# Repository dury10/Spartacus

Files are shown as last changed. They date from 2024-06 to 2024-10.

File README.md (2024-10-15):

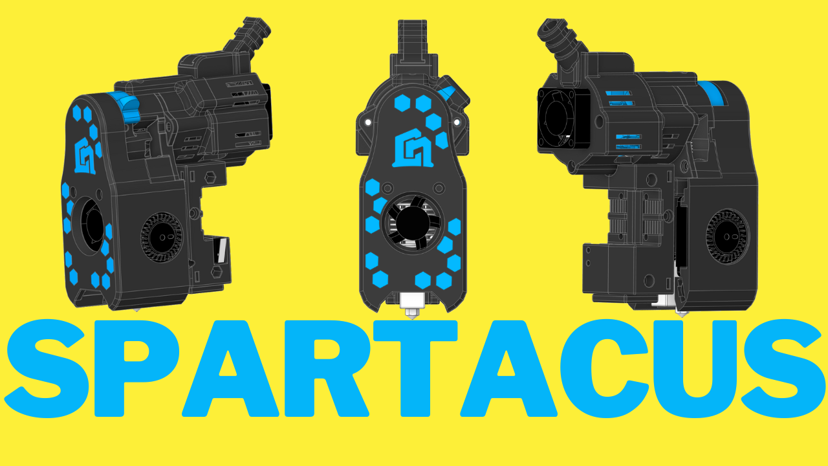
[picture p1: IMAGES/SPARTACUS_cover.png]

 
Later edit : 
added Rapido UHF as an option for the hotend 
we have added Eddy Support 
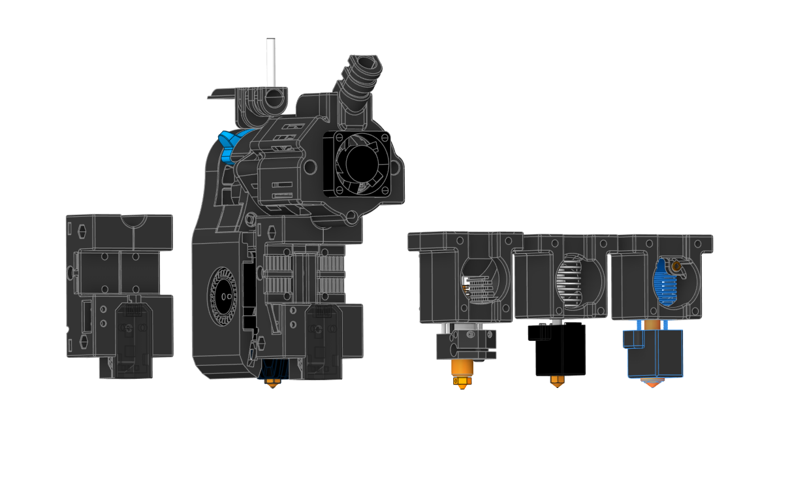
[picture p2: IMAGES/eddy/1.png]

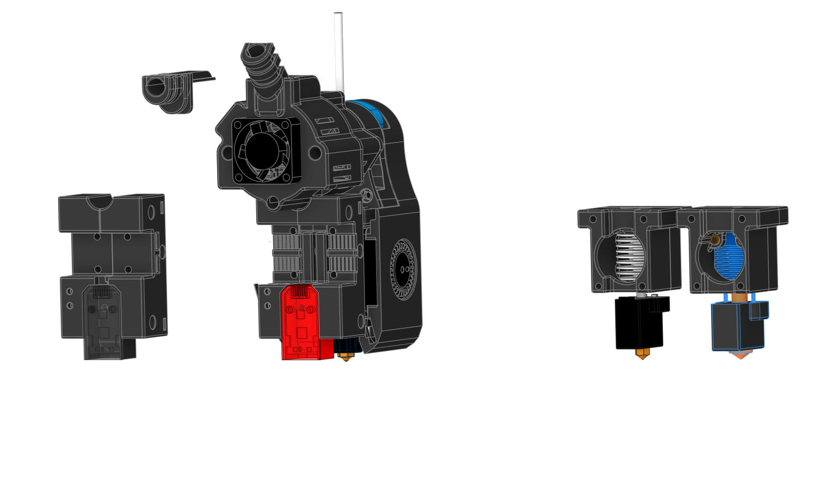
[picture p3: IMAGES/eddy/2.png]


### Hello Everyone 

This is my take on building a small toolhead:
A project I have been working on for more than a year. It all  started when Voron Design launched V0.2 with the Mini StealthBurner
I liked that toolhead a lot but I wanted more. 
More Flow, more cooling and more features like LED and this is how i ended with CN3D 4010 Mini StealtBurner.
I always liked the idea to get out the most from anything I encounter.  I looked for a way to be on the budget and to achieve better quality and reasonable speeds. 
I will not talk more about the last year project but it’s important to let you know how I got to Spartacus!

After I managed to add in MSB everything that in my opinion was missing I thought “what if i’d have all of these in a smaller and lighter form?”. And this is how I ended up with a lighter  and narrower toolhead.

### Who is this Toolhead for? 

This is for someone who wants a light toolhead that looks good ,without messy cables,  tidy and has visible and lighted nozzle, that you can build with off the shelf components that doesn’t require a lot of money. 
I found a solution for every situation i have encountered on my journey to print fast on a budget. 

### Now, to correct what i said :
I didn’t crafted all the parts that I have used to create this toolhead. I just tested a lot to find the cheapest version to achieve  the results I was aiming for. 

### I got a lot of questions about the difference from the stock design. 

- It has bigger part cooling fans. I went further and I removed the cover from the fans and used the cowling as a fan cover.
- It has 2 neopixels.
- It has built in cable management and covers to hide all the messy spaghetti.
- It has passive cooling for the stepper motor, and all the flow/air from the hotend fan is routed to go up out of the build plate.
- It has different position for the idler gear to reduce some artifacts.

### It can be installed on any Voron v2.4 or trident or any other 3d printer that uses this gantry style. 

### The design goal:
- to have all of the above in less than 320 grams 
- to have a minimum flow of 35mm3/s and all the parts used to build this toolhead to be less than 120Euros.

 Spartacus: The Toolhead stands as a testament to lightweight engineering mastery, boasting a total weight of under 320 grams, with the potential to further reduce weight by implementing titanium screws. Every component, from the stepper motor to the thermistor, board cables, heater, LEDs, fans, heatsink, nozzle, and screws, has been meticulously crafted to maintain this featherlight profile without compromising on performance or durability. Spartacus redefines the possibilities of 3D printing toolheads, offering a combination of high performance and portability that is unmatched in its class. Dominate your printing projects with Spartacus: where innovation meets lightweight precision.

 Engineered with precision, Spartacus integrates a multitude of features including dual RGBW LEDs, direct drive capabilities, and an appealing aesthetic with concealed cables and motor covers. Compatible with both EBB36 and Piggyback 36 toolboards, Spartacus offers versatility without compromise. Weighing under 320 grams, its agile form minimizes inertia, enabling rapid accelerations and pristine print quality, free from artifacts. Unleash the power of Spartacus: where innovation meets agility.

## Key Features:

- Powerful direct drive extruder for rapid printing (Flow tested up to 55mm³/s)
- Utilizes the T-Volcano hotend for increased flow and faster prints
- Enhanced cooling with 3010 and dual 4010 GDS Time 12000 rpm fans
- Lightweight and compact design inspired by Voron Design (Mini Stealth Burner)
- Cost-efficient, with a total build cost under $75
- Versatile design allows for customization and adaptation to different setups
- 2 Neopixel LED lights for improved visibility and real-time print status updates

## Bill of Materials (BOM):

### Fans:

- 1 x 3010 GDS Time 12000 rpm Fan  https://s.click.aliexpress.com/e/_Dd0TMzH 
- 2 x 4010 GDS Time Blower Fan (12000 rpm dual ball bearing recommended for optimal cooling) https://s.click.aliexpress.com/e/_DevBF23 

### Hotend Components: For the Cheapest way posible hotend up to 32mm3/s without bumping the themperature if you want more use Rapidon 

- 1 x V6 Heat Sink (light weight) https://s.click.aliexpress.com/e/_DdVmCRp 
- 1 x BiMetal Heat Break https://s.click.aliexpress.com/e/_DdDpmGx 
- 1 x T-Volcano Heat Block https://s.click.aliexpress.com/e/_DdFLdPd
- 1 x Volcano Cht Nozzle https://s.click.aliexpress.com/e/_DFfottp
- 1 x Volcano CHT Hard Nozzle  https://s.click.aliexpress.com/e/_DD5d2Bh Best Budget nozzle 
- 1 x 65W Heater Cartridge (or higher) https://s.click.aliexpress.com/e/_DB6KBBH
- 1 x Thermistor Cartridge for V6 Volcano Heater Block 3x15 (PT100 style) NTC 100K M3950 up to 320c https://s.click.aliexpress.com/e/_DDBx7IL
- 1 x Nema 14 Pancake Stepper Motor https://s.click.aliexpress.com/e/_Dk2jz6F 
- 1 x BMG Dual Driver Gear Kit https://s.click.aliexpress.com/e/_DFUPonD 
- 1 x 30mm PTFE Tube 1.9mm ID 4mm OD
- 2 x Round PCB LED (WRGB, RGB, RGBW, WWRGB, etc.)  https://s.click.aliexpress.com/e/_DCkqzJz
- 1 x Ebb 36 Can boad https://s.click.aliexpress.com/e/_DkBHGcb 

### Optional Add-ons:

- Piggyback/Breakout Board ($9) 
- End caps for cable management based on your setup and chosen board an some cable management wrap 
- 1 x PT1000 Probe 3mm * 15mm Up to 450 Degree RTD 1m Platinum Thermal Resistance Sensor For 3D Printer Volcano/ V6 Heater Block https://s.click.aliexpress.com/e/_DeoYaER 

### Nozzle / Hotend Options (Optional, depending on preference):

- Volcano Cht Nozzle https://s.click.aliexpress.com/e/_DFfottp
- Volcano CHT Hard Nozzle  https://s.click.aliexpress.com/e/_DD5d2Bh Best Budget nozzle 
- Rapido UHF added https://s.click.aliexpress.com/e/_DdN6yC7  
  
## Hardware:

### Heatset Inserts:

- 1 x M3 x 5.7 x 4.5/4.6 Heatset Insert
- 8 x M3 x 3 x 4.5 Heatset Insert

### M3 Screws:  

- 3 x M3 x 6
- 5 x M3 x 10
- 3 x M3 x 25
- 1 x M3 Hex Nut
M3  Screws Kit https://s.click.aliexpress.com/e/_DBdNTVD   

#### This versatile and feature-packed 3D printer tool head provides an affordable solution for high-quality, high-speed printing, enhanced by Neopixel LED lights for improved visibility and dynamic print status updates.

#### Assembly of Spartacus requires minimal tools, including an 1.5mm drill bit, a drill, an angle grinder or hacksaw, and 1.5, 2 and 2.5mm Allen keys. With these tools, users can effortlessly assemble Spartacus and unleash its full potential.

### Here you can see how to build this Awesome Toolead

SPARTACUS (https://www.youtube.com/watch?v=S5xbkWCNOBw)

### If you want to see it in action you can see it here

SPARTACUS (https://www.youtube.com/shorts/Fdcm6XfQ08U)

##  <a href="assembly.md"  >  Assembly guide</a>

If you want to see it in action you will find videos on Tiktok  and Youtube
#### You can follow us on

### Tiktok https://www.tiktok.com/@3dprinttutorials

### Youtube https://www.youtube.com/@nadir3D 

### Facebook https://www.facebook.com/CN3DP/

### Printables https://www.printables.com/@Nadir

CN3D Spartacus is licensed under the
GNU General Public License v3.0
Permissions of this strong copyleft license are conditioned on making available complete source code of licensed works and modifications, which include larger works using a licensed work, under the same license. Copyright and license notices must be preserved. Contributors provide an express grant of patent rights.

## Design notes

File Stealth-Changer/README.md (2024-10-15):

  StealthChanger
**Tool changing system for Sovol SV08 / Vorons and other front mount printer motion systems.**

Here you can find Back Plates to can install Spartacus the toolhead on your Stealt-Changer
keep an eye on this repository more updates to come!
* I want to make this clear here you will find only the parts to can use Spartacus as a toolhead. 
* The toolchanger sistem is not made by us and we don't want to take credit for it! This is the work of the DraftShift theam https://github.com/DraftShift/StealthChanger

Our file that are 100% open source and are work in progress. Spartacus BMG is free and we have listed also the cad file for it. 

<div align="center">
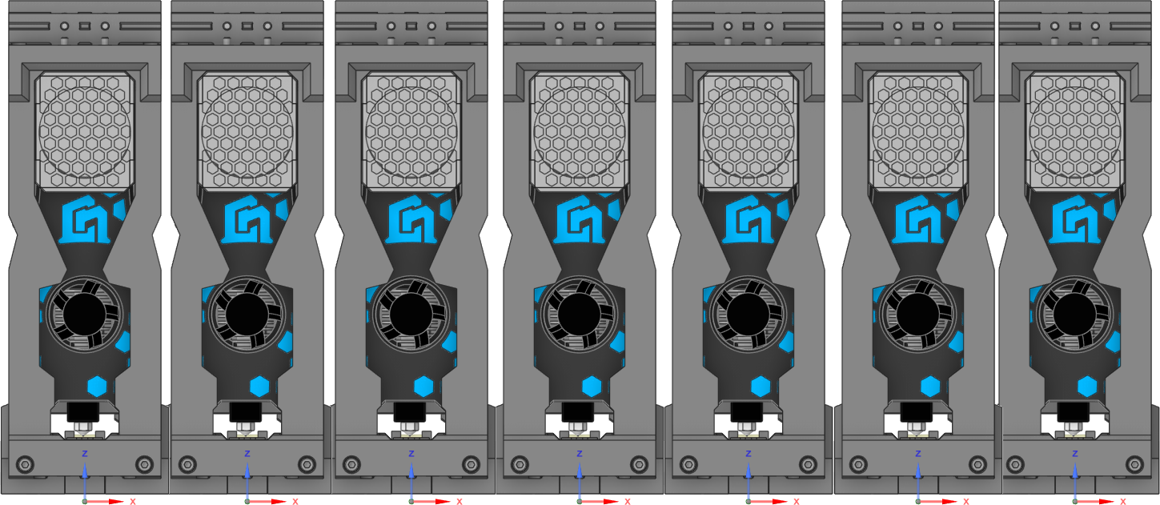
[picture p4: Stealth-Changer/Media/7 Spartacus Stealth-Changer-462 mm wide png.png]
  
</div>

## The Dock is 66mm Wide the Spartacus toolhead is 53 mm wide and 116 mm height  
<div align="center">
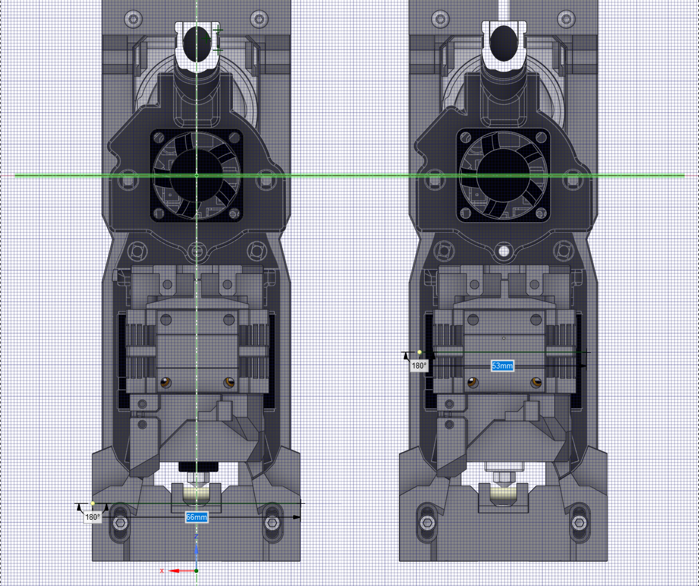
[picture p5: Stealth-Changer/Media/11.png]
 
</div>

 <table border="0"> 
        <tr> 
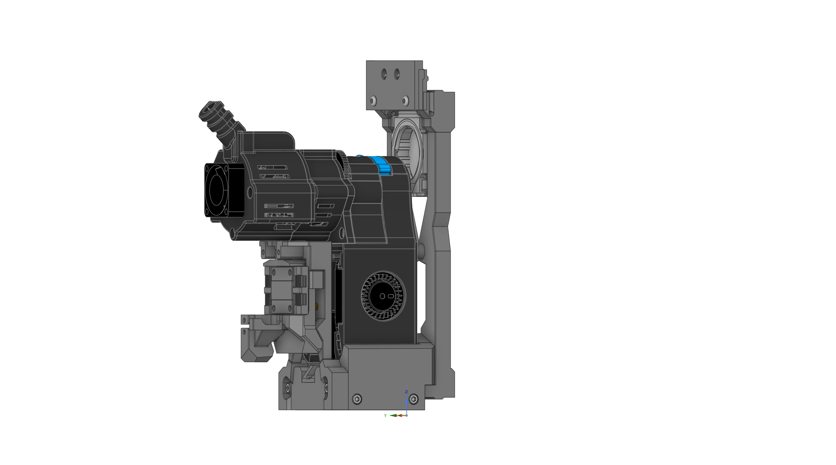
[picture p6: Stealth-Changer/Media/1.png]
            <th></th> 
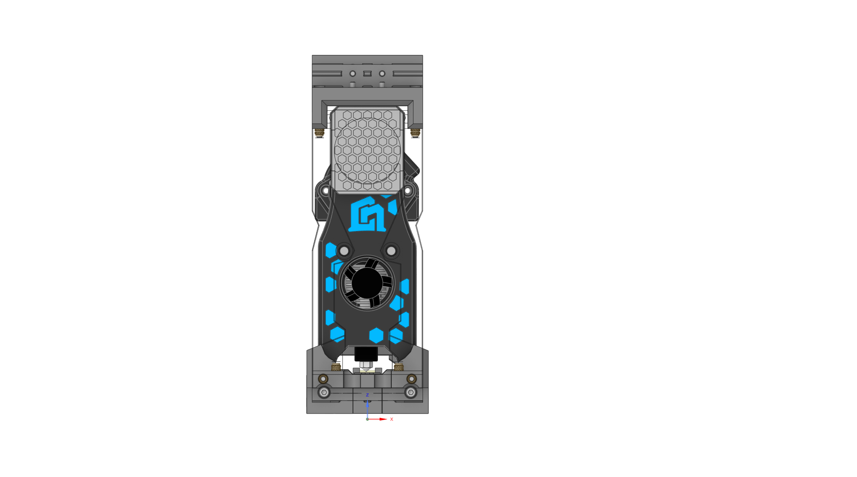
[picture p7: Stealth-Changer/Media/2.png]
            <th></th> 
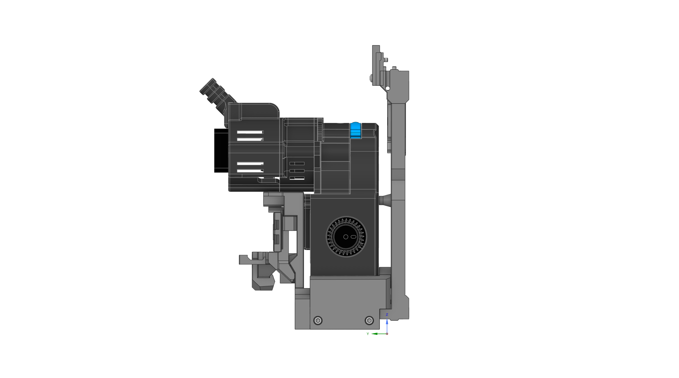
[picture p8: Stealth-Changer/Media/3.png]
            <th></th> 
        </tr> 
        <tr> 
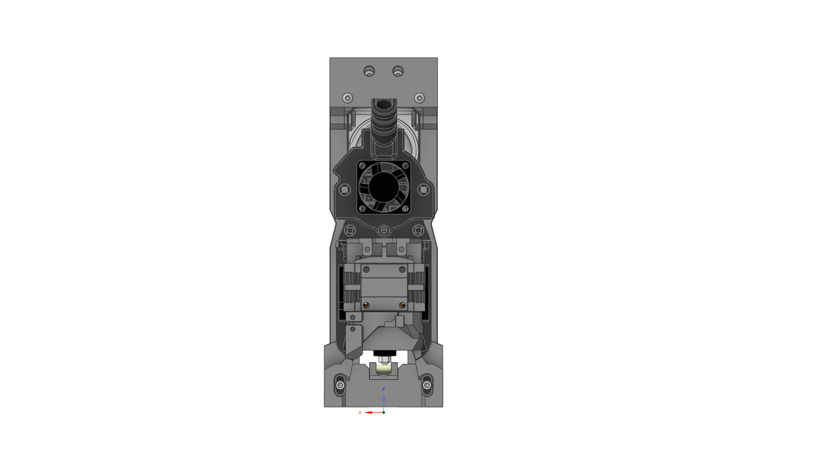
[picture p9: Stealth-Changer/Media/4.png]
            <td> </td> 
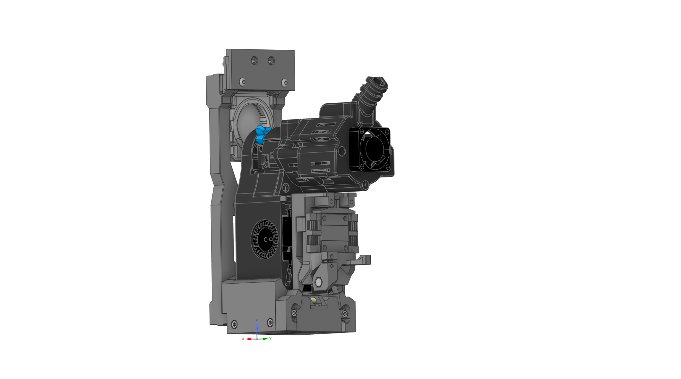
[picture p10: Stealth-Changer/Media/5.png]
            <td></td> 
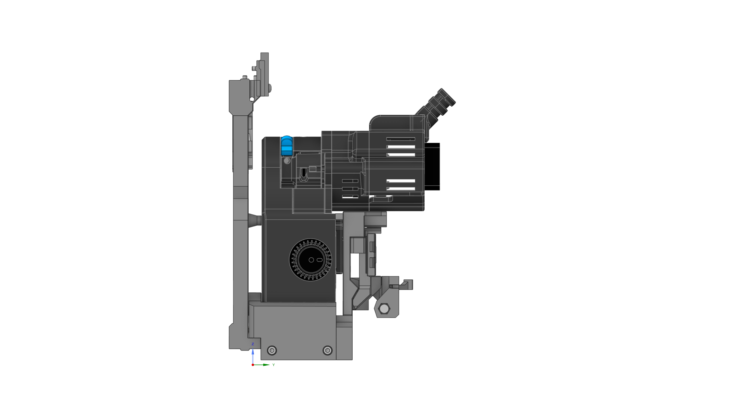
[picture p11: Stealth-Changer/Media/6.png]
            <td> </td> 
        </tr> 
        <tr> 
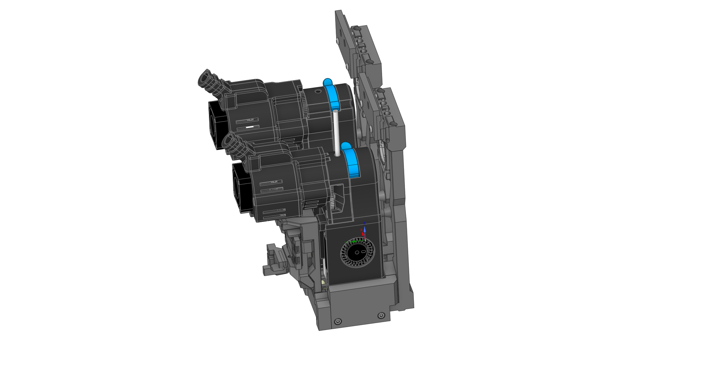
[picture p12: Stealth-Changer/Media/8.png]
            <td>  </td> 
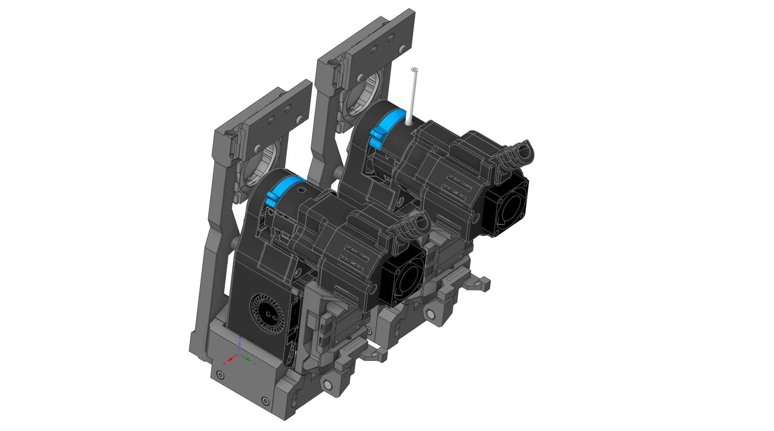
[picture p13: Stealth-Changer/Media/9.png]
            <td></td> 
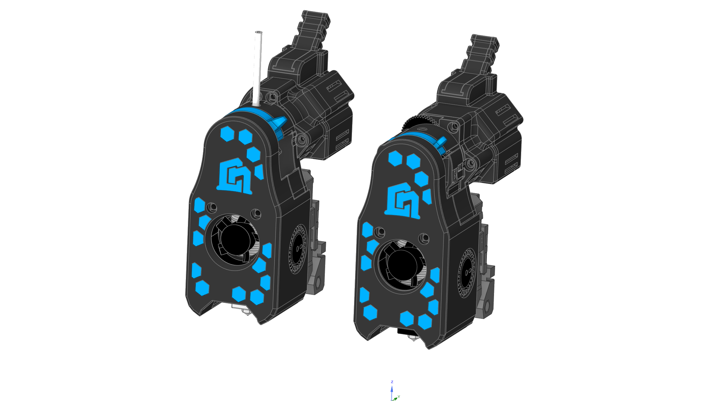
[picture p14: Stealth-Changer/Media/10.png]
            <td>  </td> 
        </tr> 
         <tr> 
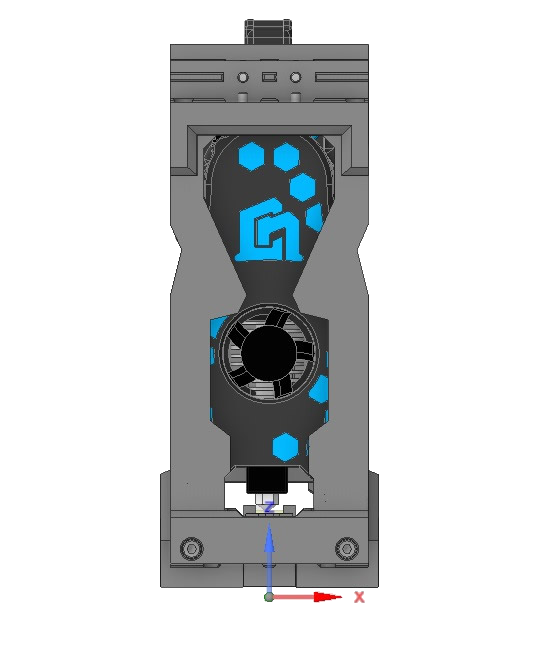
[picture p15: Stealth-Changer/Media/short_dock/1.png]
            <td>  </td> 
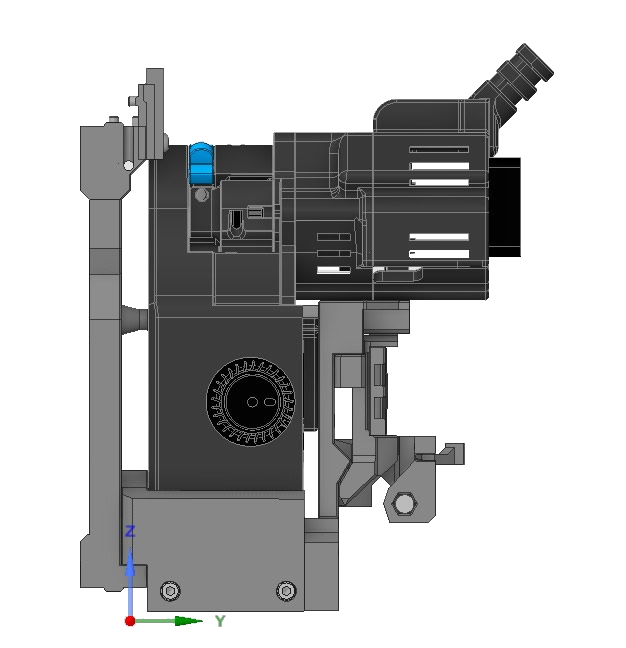
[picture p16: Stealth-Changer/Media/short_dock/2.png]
            <td></td> 
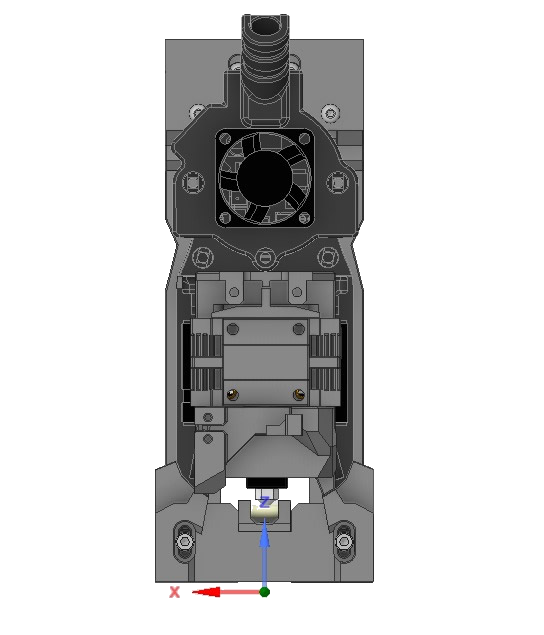
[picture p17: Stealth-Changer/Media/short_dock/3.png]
            <td>  </td> 
        </tr> 
              <tr> 
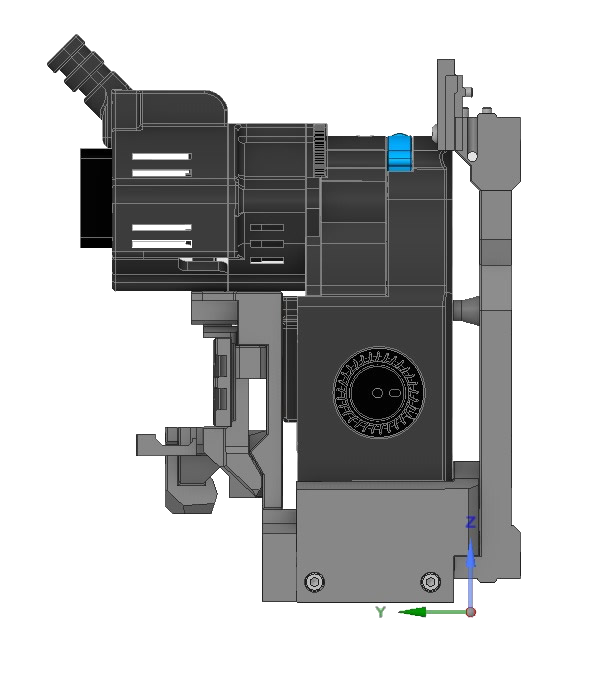
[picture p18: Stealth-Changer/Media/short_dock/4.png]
            <td>  </td> 
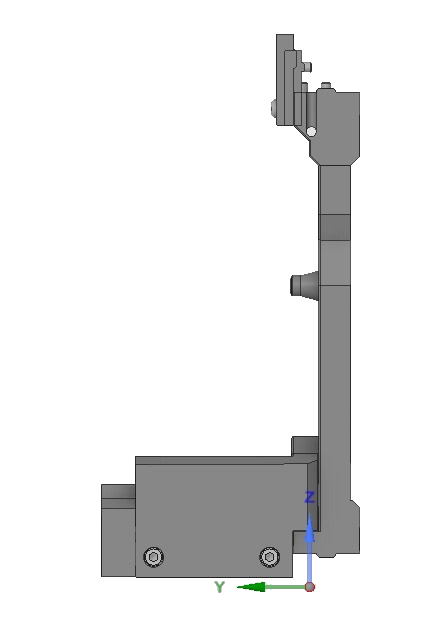
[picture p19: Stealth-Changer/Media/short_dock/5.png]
            <td></td> 
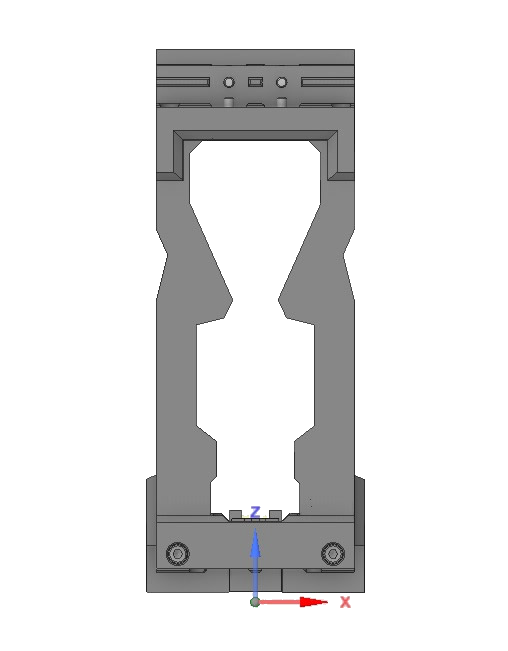
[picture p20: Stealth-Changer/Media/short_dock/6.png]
            <td>  </td> 
        </tr> 

<tr> 
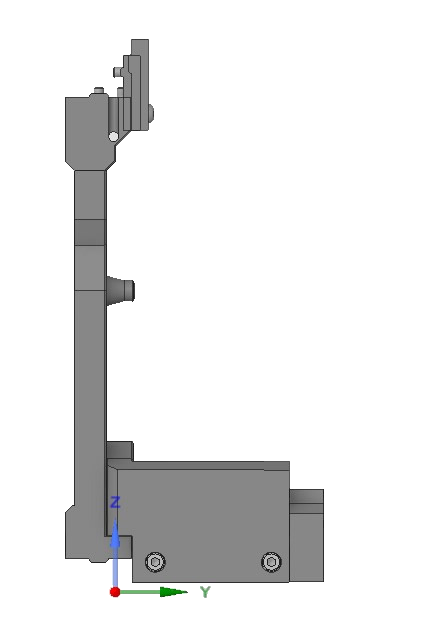
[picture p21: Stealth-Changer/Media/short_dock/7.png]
            <td>  </td> 
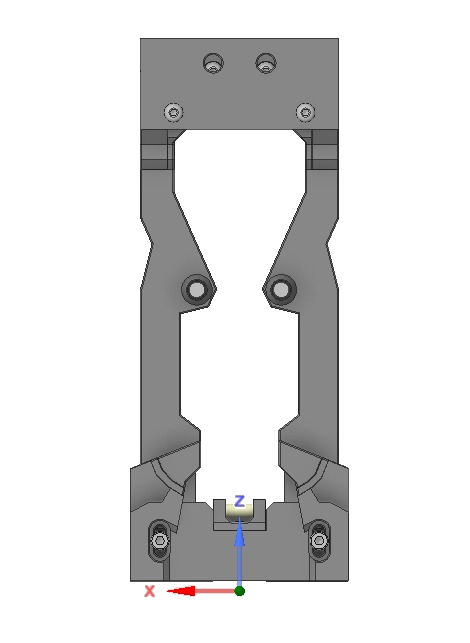
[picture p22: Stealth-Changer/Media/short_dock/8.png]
            <td> </td> 
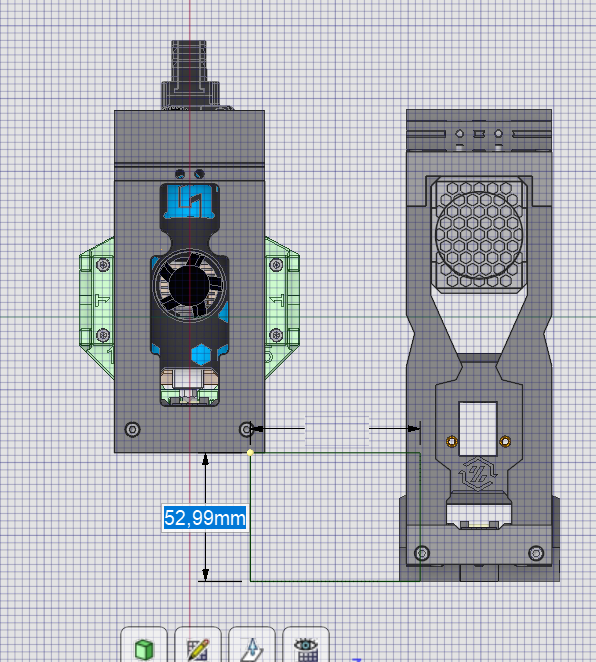
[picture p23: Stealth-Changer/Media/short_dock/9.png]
            <td>  </td> 
 </tr> 

</table> 

* Here you can have hi-quality STL for Spartacus BMG
https://www.printables.com/model/745412-spartacus-the-toolhead

* Here you can have hi-quality STL for Spartacus LGX
https://www.printables.com/model/900809-spartacus-lgx

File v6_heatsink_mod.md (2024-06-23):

## <p align="left">Step by step how to modify your V6 heatsink to fit Spartacus and to be more secure </p>

### 

<br clear="both">

<p>here we have the most common V6 heatsinks</p>
<div align="center">

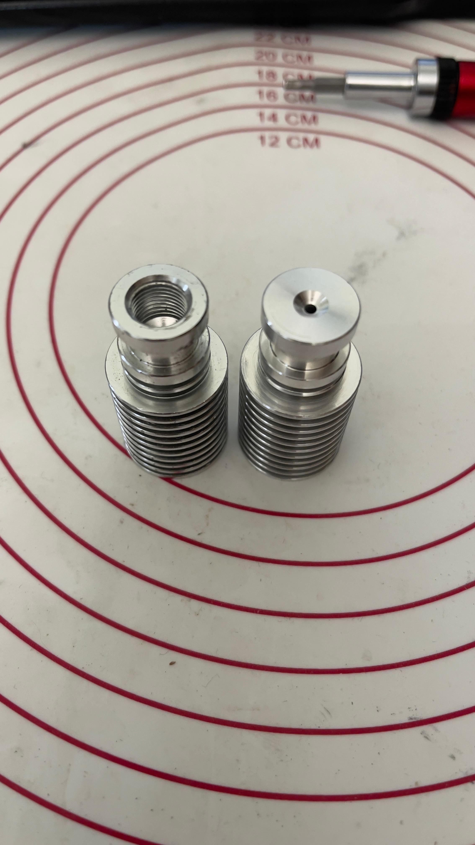
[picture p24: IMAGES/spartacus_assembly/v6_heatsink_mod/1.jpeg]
  
</div>

<p>Bowden and Direct drive Style </p>

<div align="center">
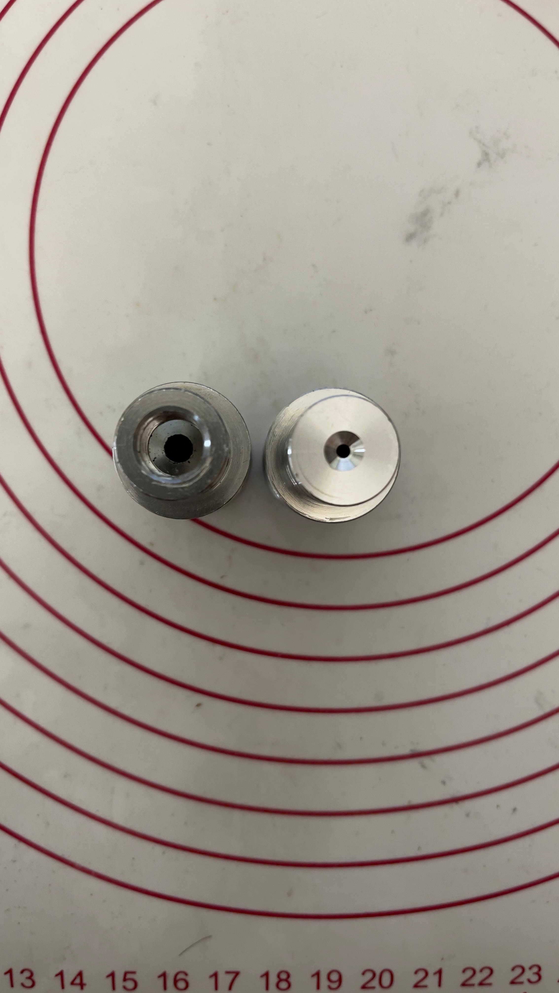
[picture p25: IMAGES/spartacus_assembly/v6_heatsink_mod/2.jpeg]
  
</div>

<p>As dimension they are the same</p>

<div align="center">
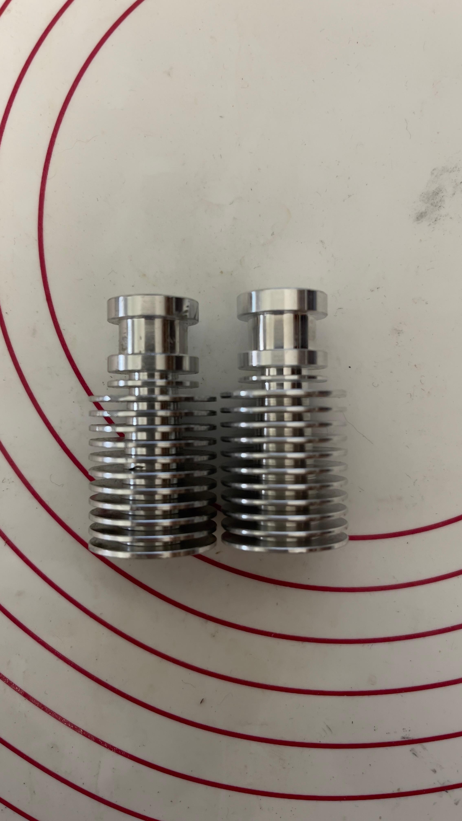
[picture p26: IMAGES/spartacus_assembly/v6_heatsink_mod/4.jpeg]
  
</div>

<p>Here is where we will make the cut</p>

<div align="center">
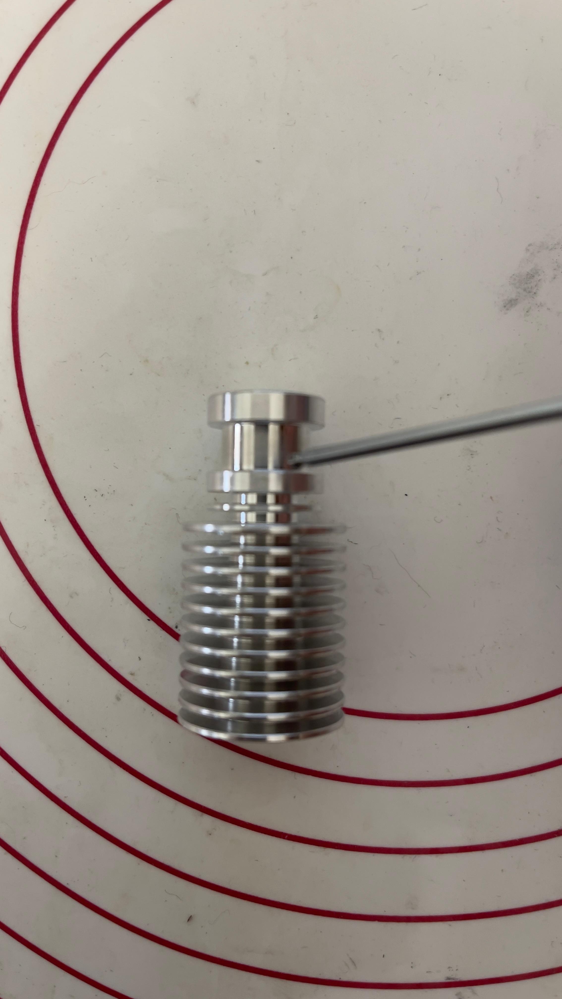
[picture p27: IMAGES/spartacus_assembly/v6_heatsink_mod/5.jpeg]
  
</div>

<p>I have used an angle grinder to cut the upper part, but you can use a hack saw </p>
<div align="center">
  
     

</div>

<p>This is how it is supposed to like after the cut</p>
<div align="center">
  
</div>

<div align="center">
  
</div>

<div align="center">
  
</div>

<p>As you can see i prefer the bowden stile heat sink</p>
<div align="center">
  
</div>

<div align="center">
  
</div>

<div align="center">
  
</div>

<p>Put the heatsink in the V6 Holder </p>
<div align="center">
  
</div>

<div align="center">
  
</div>

<div align="center">
  
</div>

<p>And use 2 M3x40 screw + 2x M3 nuts to secure it in place </p>
<div align="center">
  
</div>

<div align="center">
  
</div>

<div align="center">
  
</div>

<div align="center">
  
</div>

<p>Use a 2.5mm Dril bit and drill 2 holes in the designated locations </p>

<div align="center">
  
</div>

<div align="center">
  
</div>

<div align="center">
  
</div>

<div align="center">
  
</div>

<div align="center">
  
</div>

<p>Clean the debrie and prepare your M3 TAP </p>
<p>Carefully cut some treads 3-5mm </p>

<div align="center">
  
</div>

<div align="center">
  
</div>

<p>After cleaning the threads, now you can screw 2x M3x4, M3x5 or M3x6 I prefer the M3x4 saving weight. </p>

<div align="center">
  
</div>

<p>Remove everything and clean all the mess </p>
<div align="center">
  
</div>

<div align="center">
  
</div>

<p>It should look like this</p>

<div align="center">
  
</div>

<div align="center">
  
</div>

<div align="center">
  
</div>

# <a href="toolhead_assembly.md#Spartacus">Congratuletion now let's asamble the toolhead </a>

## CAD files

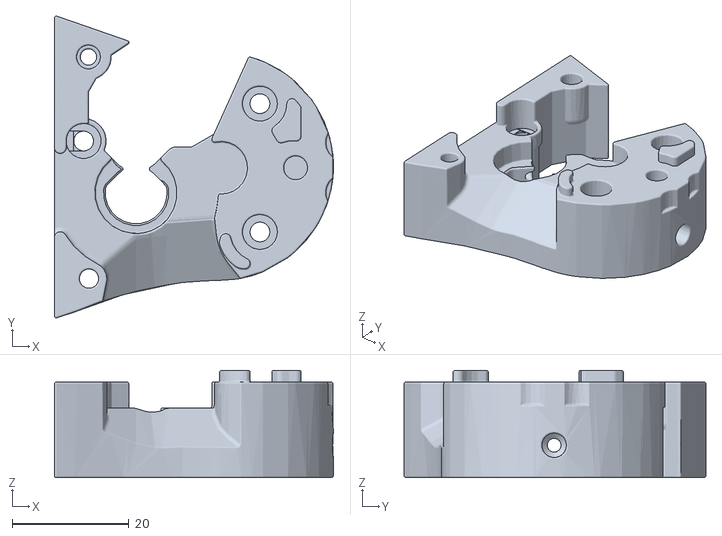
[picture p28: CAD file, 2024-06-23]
STL/extruder_main_body.stl
47.8 x 51.8 x 18.4

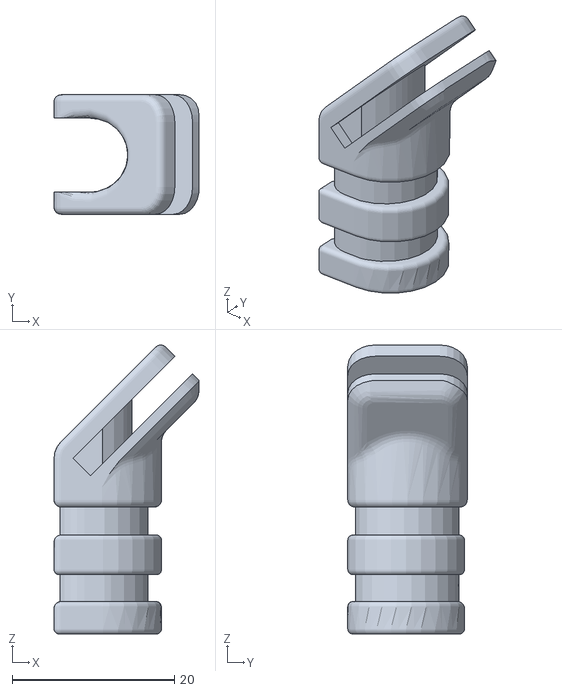
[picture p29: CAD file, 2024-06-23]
STL/strain_relief_45_degres.stl
17.8 x 14.7 x 35.6

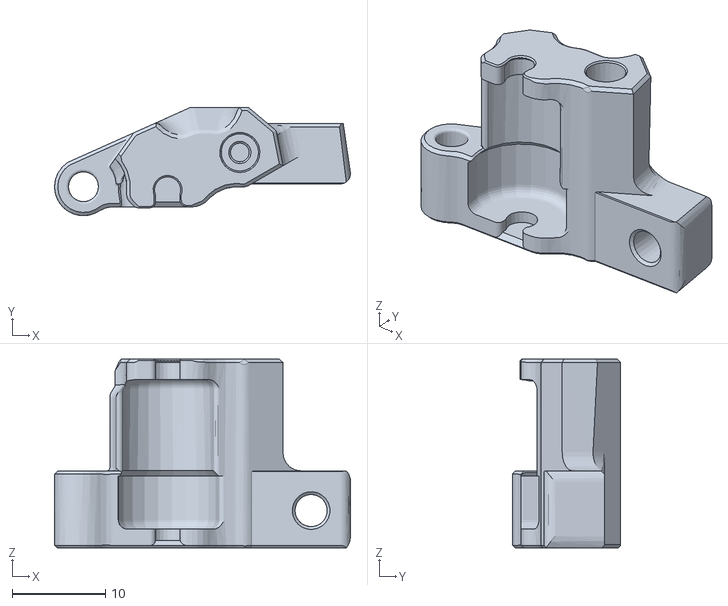
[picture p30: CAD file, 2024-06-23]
STL/idler.stl
31.7 x 11.6 x 20.2

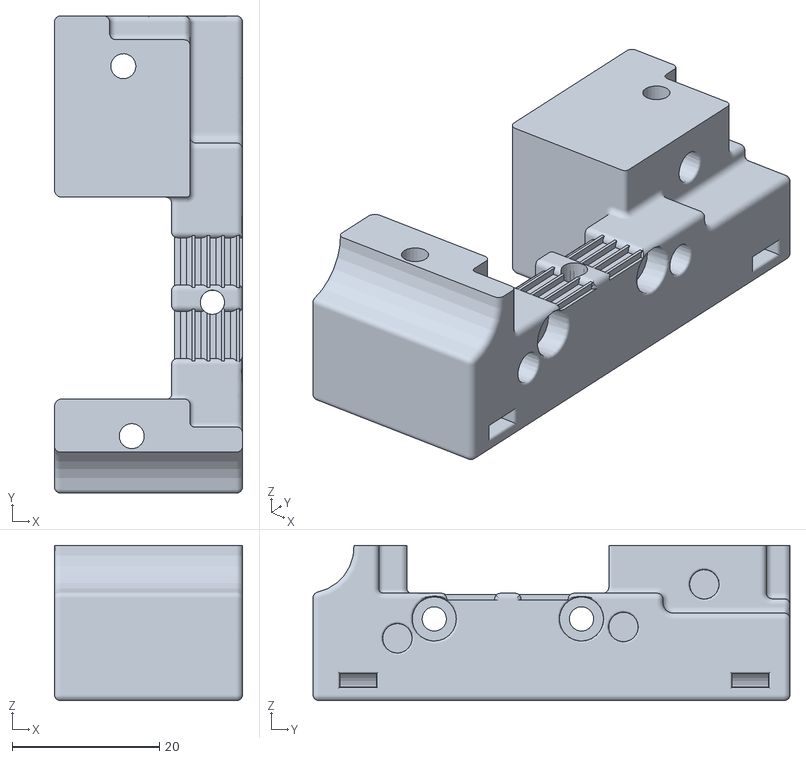
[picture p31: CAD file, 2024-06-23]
STL/MGN12_6mmBelt_X_carriage_Left.stl
25.5 x 64.8 x 21.1

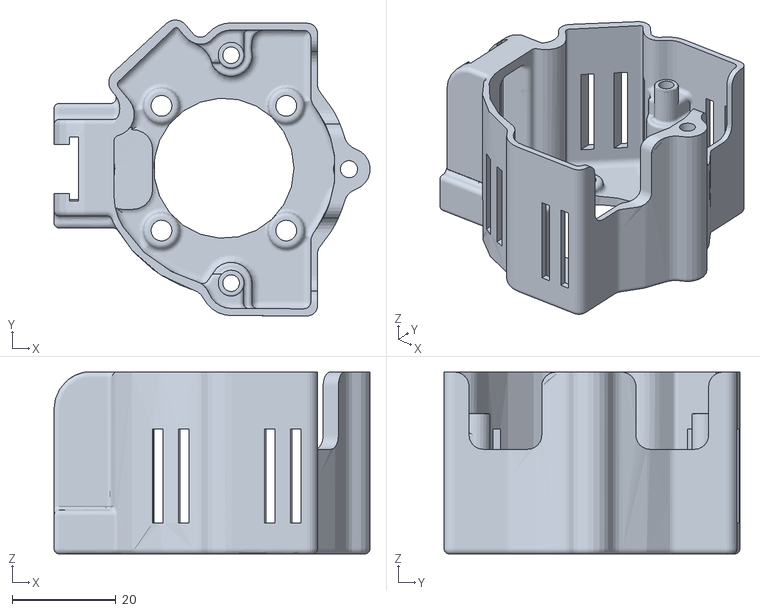
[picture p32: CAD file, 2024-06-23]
STL/ebb_36_can_cover.stl
60.8 x 56.9 x 35.0

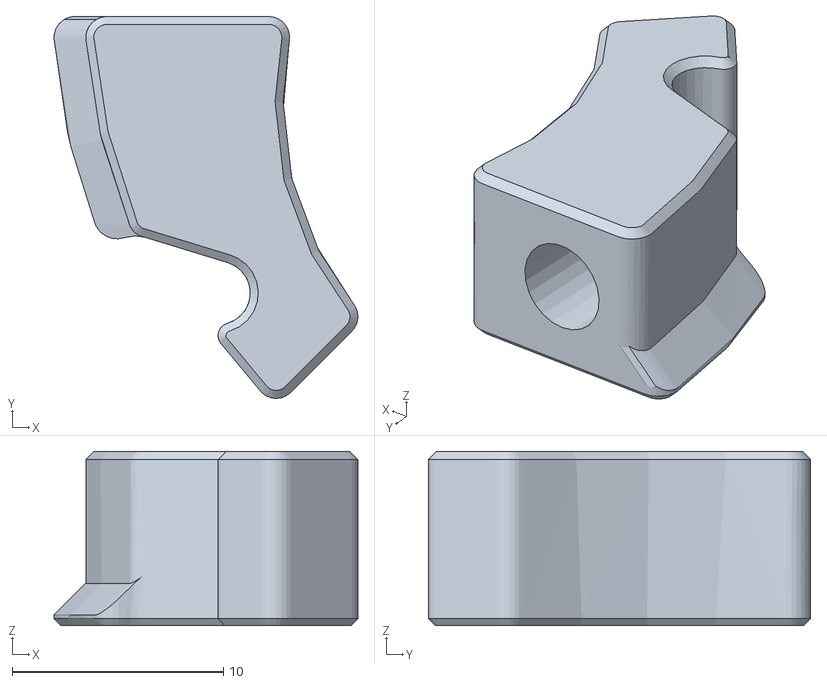
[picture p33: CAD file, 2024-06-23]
STL/shutter.stl
14.4 x 18.1 x 8.25

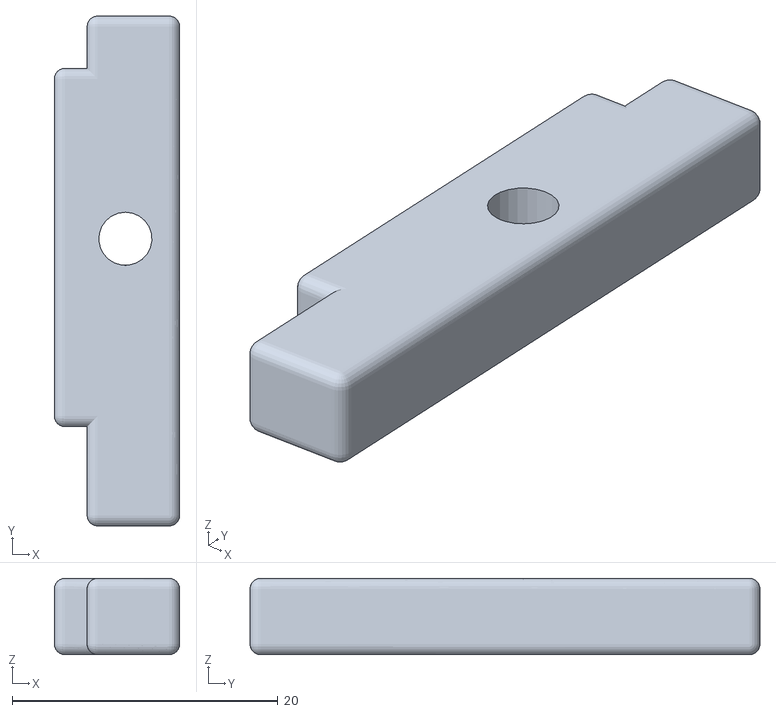
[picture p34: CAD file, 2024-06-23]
STL/belt_holder_x2.stl
9.44 x 38.4 x 5.75

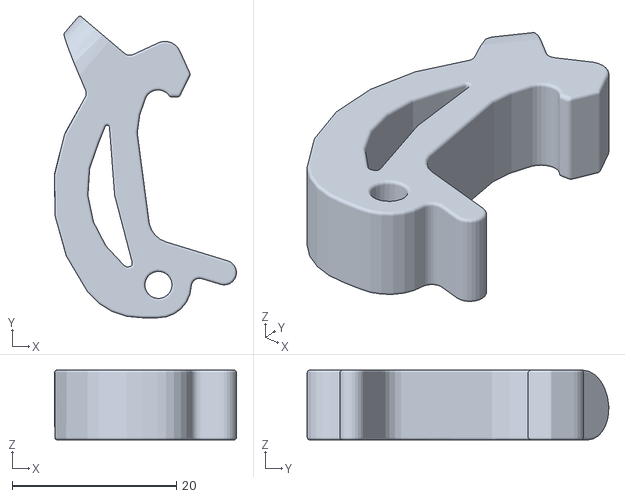
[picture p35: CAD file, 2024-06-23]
STL/latch.stl
22.2 x 36.7 x 8.50

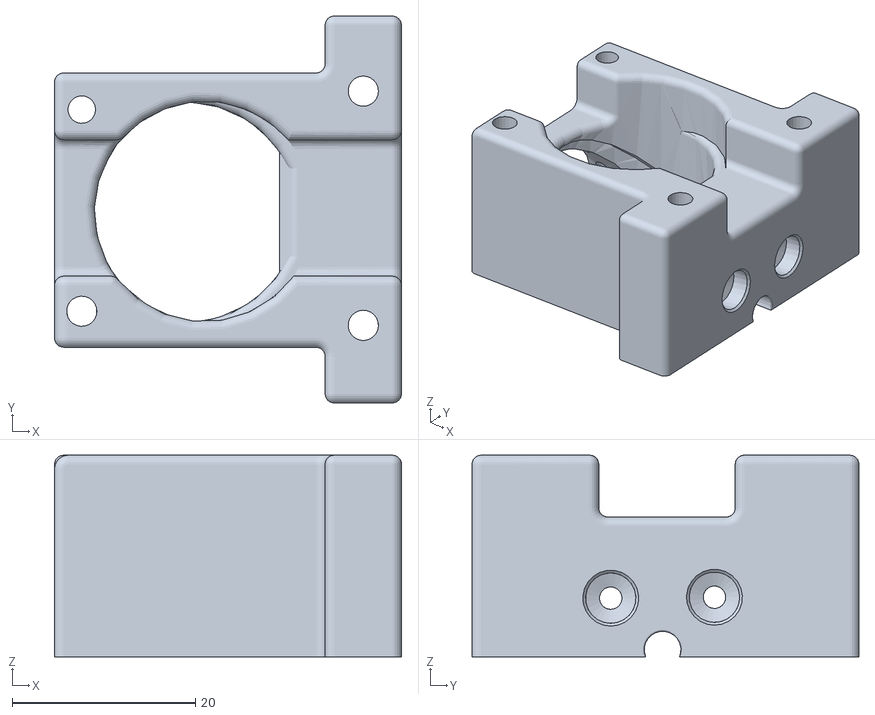
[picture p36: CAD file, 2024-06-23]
STL/rapido_holder_back.stl
37.9 x 42.2 x 22.0

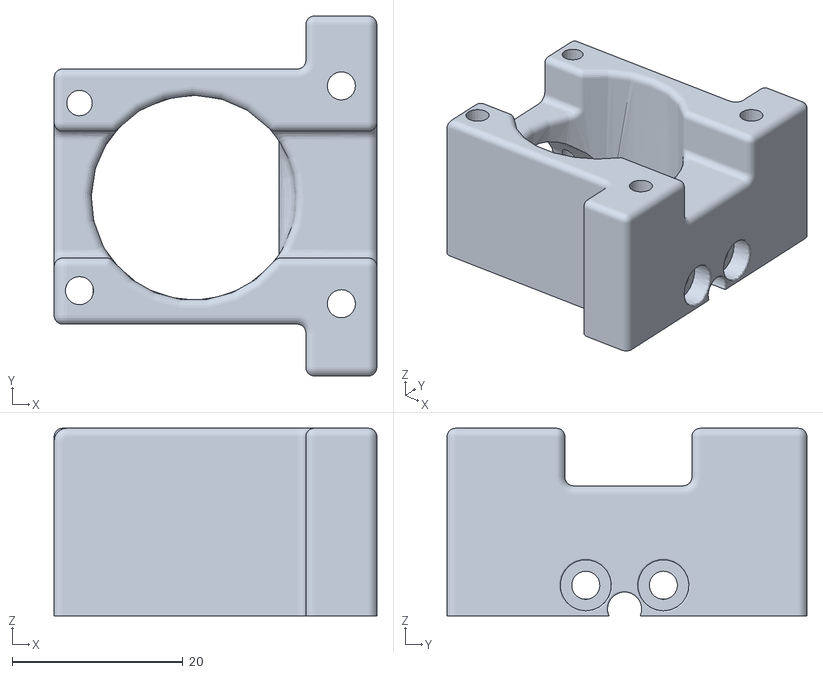
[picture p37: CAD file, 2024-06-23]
STL/v6_holder_back.stl
37.9 x 42.2 x 22.0

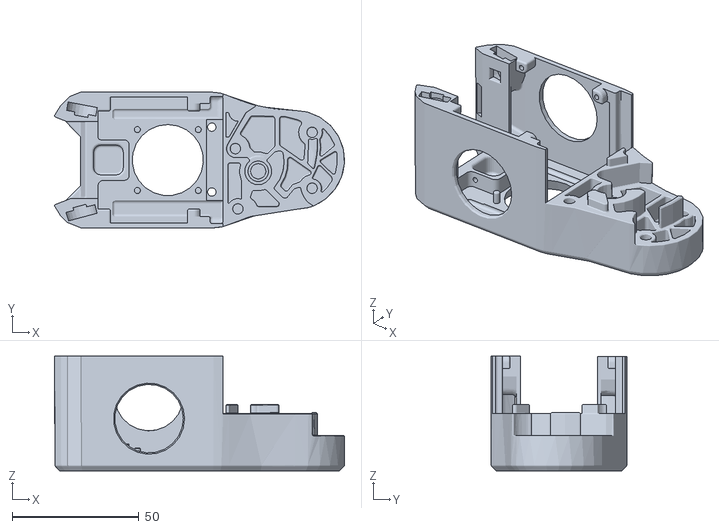
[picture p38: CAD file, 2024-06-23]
STL/Spartacus_Face.stl
114.2 x 53.5 x 45.3

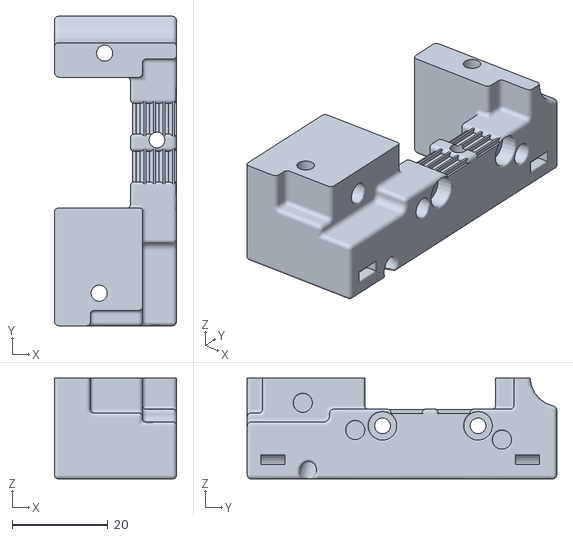
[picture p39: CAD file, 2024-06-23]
STL/MGN12_6mmBelt_X_carriage_Right.stl
25.5 x 64.8 x 21.1

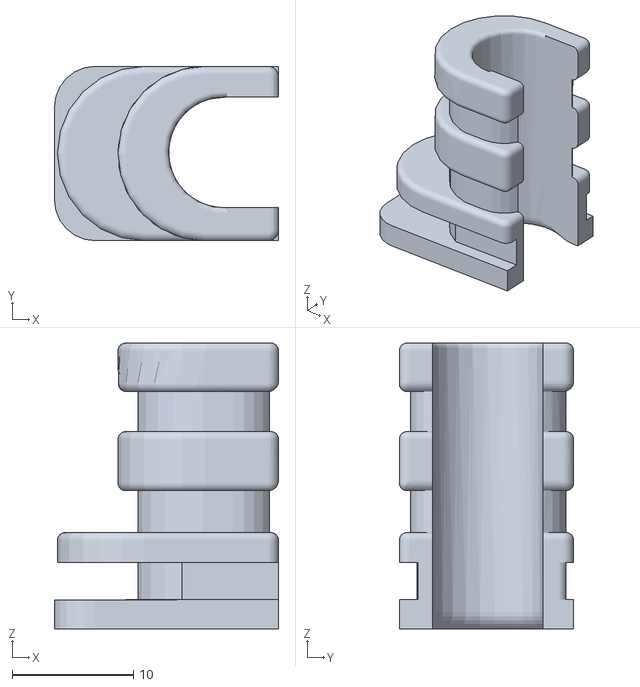
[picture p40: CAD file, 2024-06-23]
STL/strain_relief_90_degres.stl
18.5 x 14.4 x 23.6

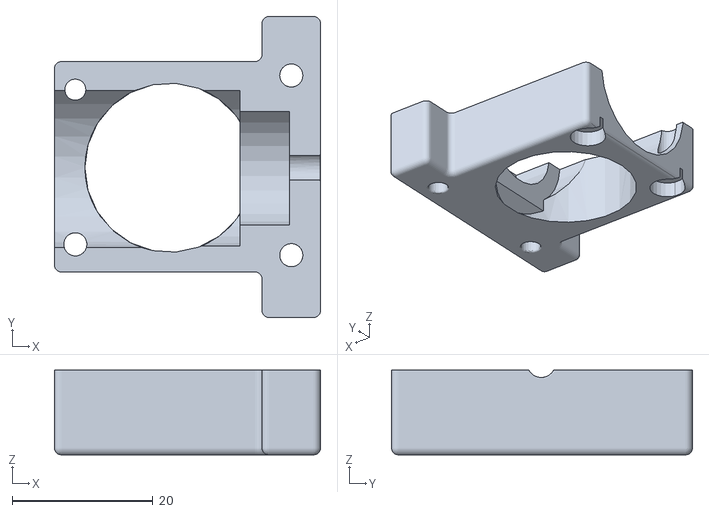
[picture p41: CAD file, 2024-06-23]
STL/V6_holder_front.stl
37.9 x 42.8 x 12.1

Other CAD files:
STL/rapido_holder_front.stl
STL/klicky_dock.stl
STL/klicky.stl
STL/strain_relief_90_degres_cover.stl
STL/extruder_back_plate.stl
STL/klicky_holder.stl
STL/stepper_motor_cover.stl
STL/strain_relief_45_degres_cover.stl

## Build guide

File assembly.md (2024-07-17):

<p align="left">Spartacus Assembly Guide </p>

Now we have added Rapido support so you dont need to do this mod fo the heatsink so skip to the assembly.
And we have also added the posibility to use the Creality stile Heatsink that came with the T-Volcano heat block that we recommend. 
https://github.com/dury10/Spartacus/blob/main/toolhead_assembly.md#t-volcano-heatsinkhotend

##   <a href="v6_heatsink_mod.md" > Here you can find how to modify the heatsink if you go with the V6 heatsink </a>
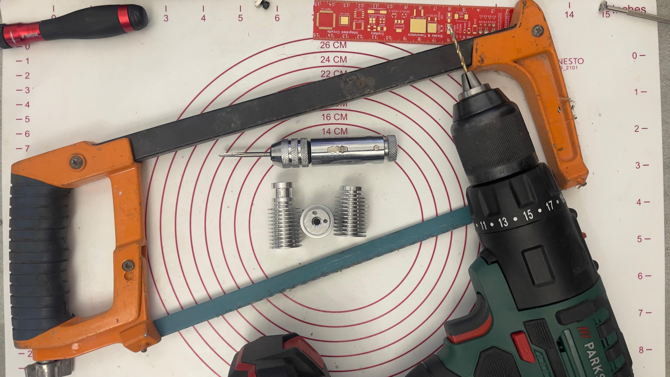
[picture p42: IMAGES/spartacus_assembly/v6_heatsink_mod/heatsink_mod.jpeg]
###  

##   <a href="toolhead_assembly.md" > Here is the guide how to assamble the tooldead  </a>
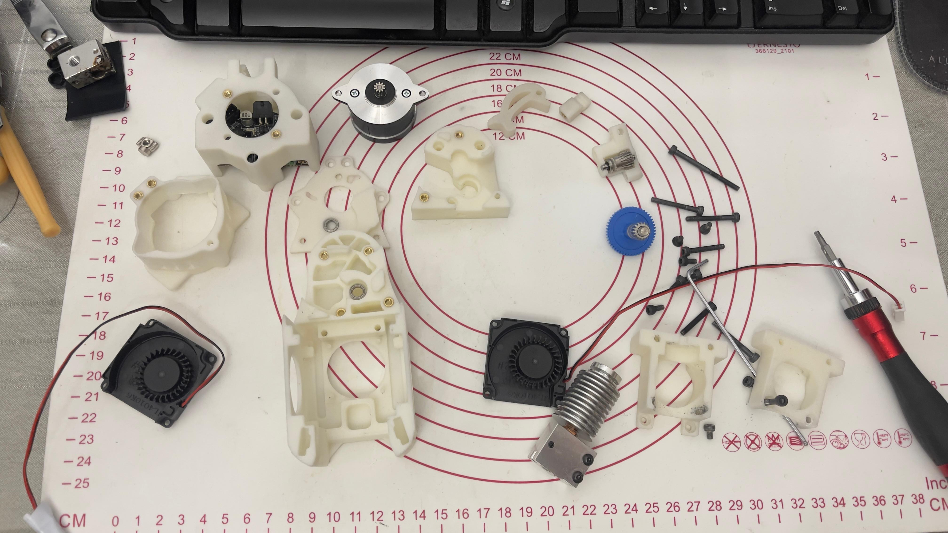
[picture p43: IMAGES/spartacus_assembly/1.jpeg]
###

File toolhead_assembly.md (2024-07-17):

<br clear="both">

<div align="center">
  
</div>

####   <a href="v6_heatsink_mod.md"> First you need to modify the heatsink </a>
####  

<br>
<br>
<br clear="both">

<h2 id="Spartacus">## Let's Start the build! </h2>

Lets put toghether the hotend. Inset the heatbrake Ideal to be bimetalic and screw the Volcano heat bloke 
<div align="center">
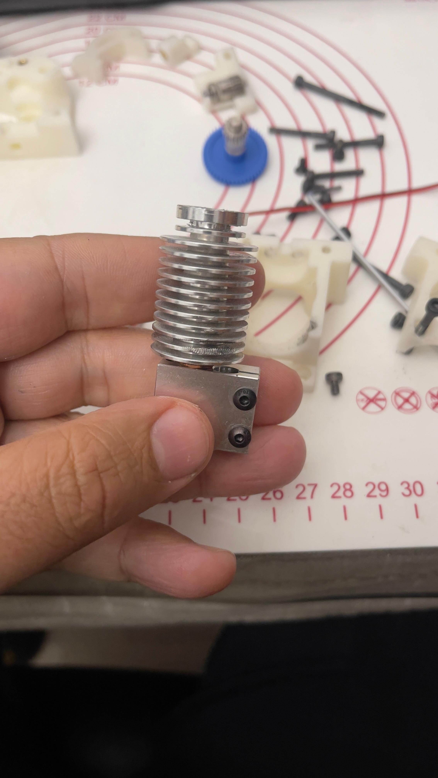
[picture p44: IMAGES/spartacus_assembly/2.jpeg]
  
</div>

With the 3 hole that we just made put them in V6_holder_back.stl
<div align="center">
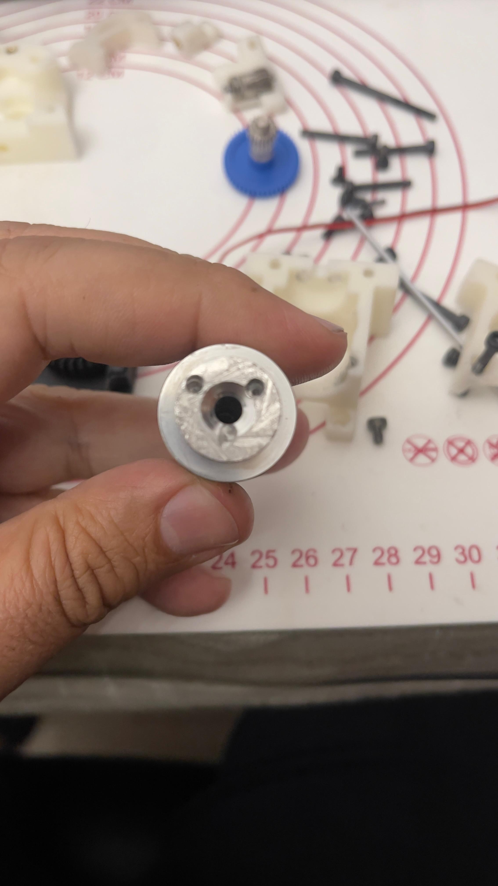
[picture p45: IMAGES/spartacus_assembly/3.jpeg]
  
</div>

<div align="center">
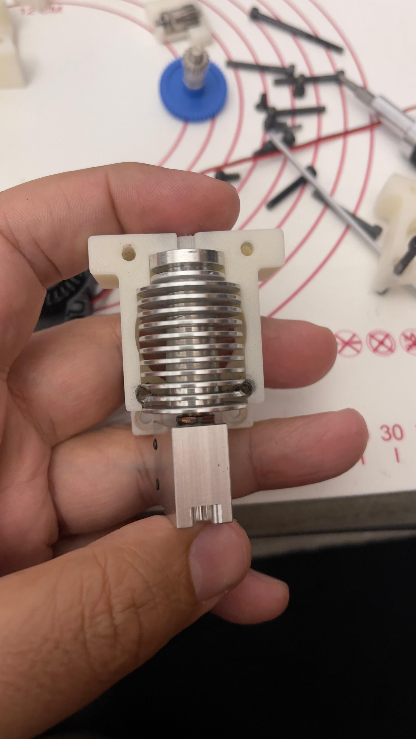
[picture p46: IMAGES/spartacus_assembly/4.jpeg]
  
</div>

<div align="center">
  
</div>

Use 2x M3x4 to secure the heatsink but don't titen them yes
<div align="center">
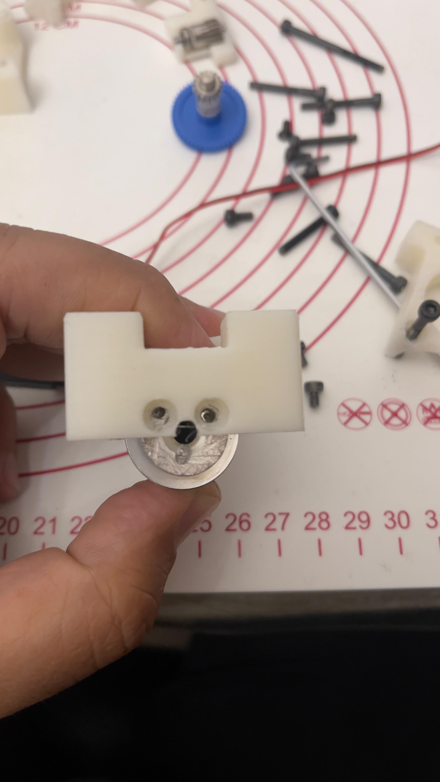
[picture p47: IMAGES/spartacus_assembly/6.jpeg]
  
</div>

<div align="center">
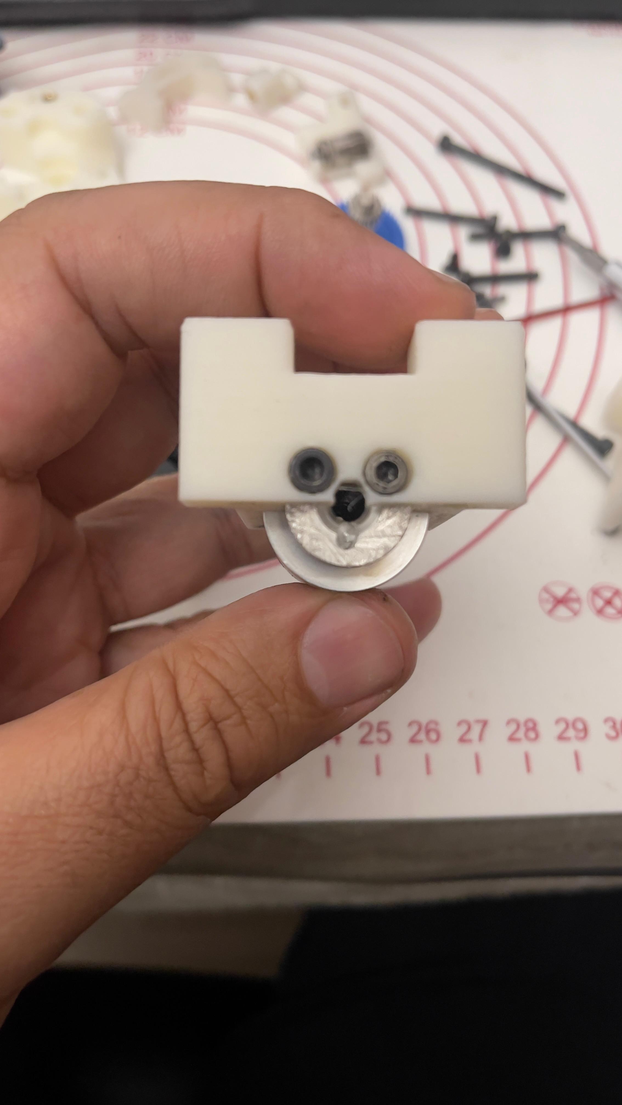
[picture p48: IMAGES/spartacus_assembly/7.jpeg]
  
</div>

<div align="center">
  
</div>

# T-Volcano Heatsink/hotend 

<div align="center">
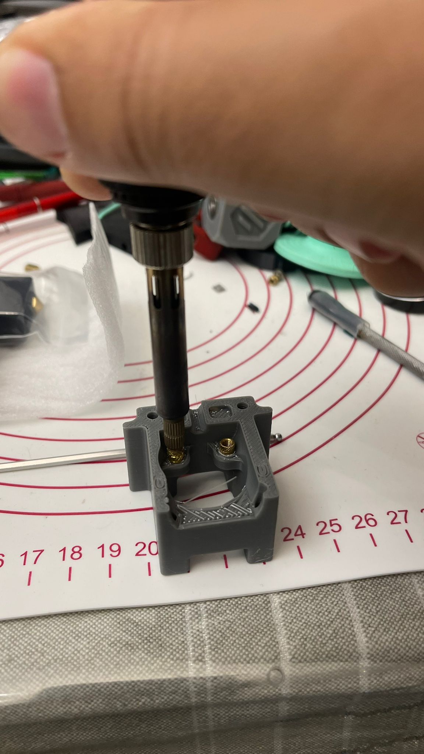
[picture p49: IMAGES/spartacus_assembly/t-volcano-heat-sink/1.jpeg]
  
</div>

<div align="center">
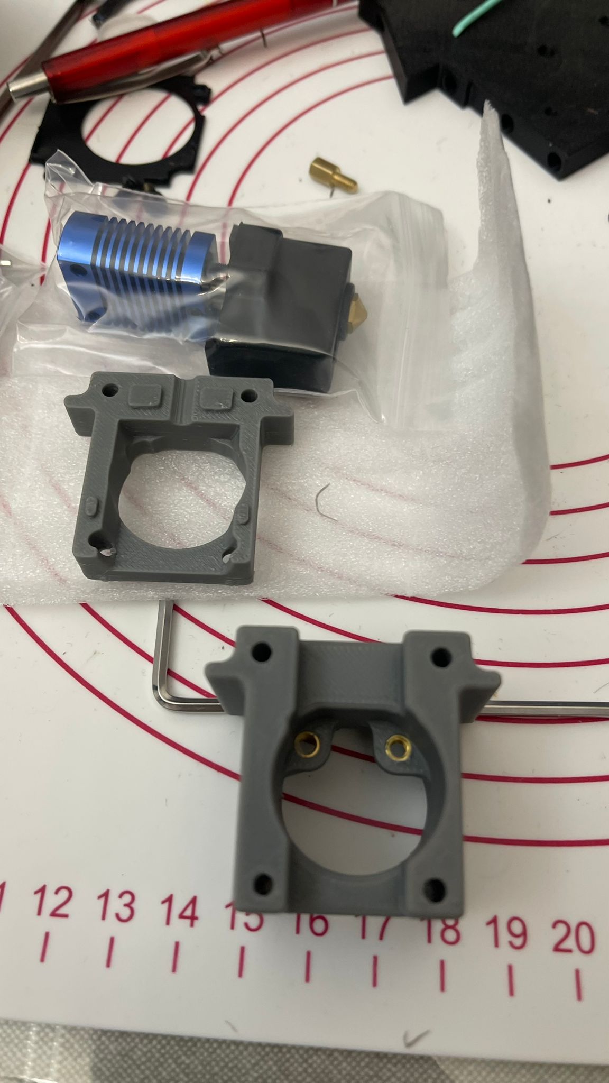
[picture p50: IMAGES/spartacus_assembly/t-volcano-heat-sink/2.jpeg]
  
</div>
<div align="center">
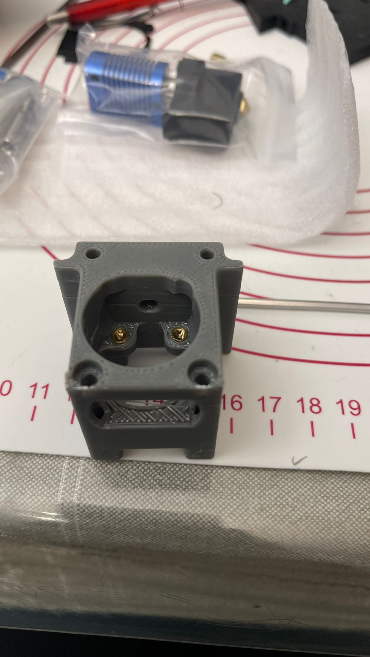
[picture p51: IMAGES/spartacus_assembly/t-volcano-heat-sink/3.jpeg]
  
</div>
<div align="center">
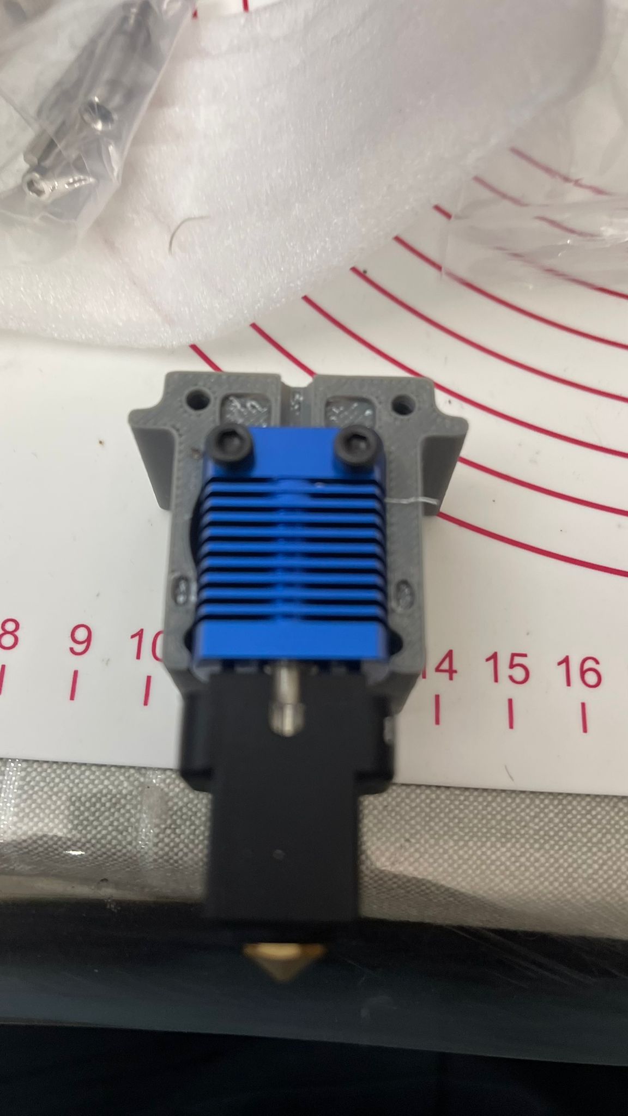
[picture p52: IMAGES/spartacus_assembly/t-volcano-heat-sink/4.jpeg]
  
</div>
<div align="center">
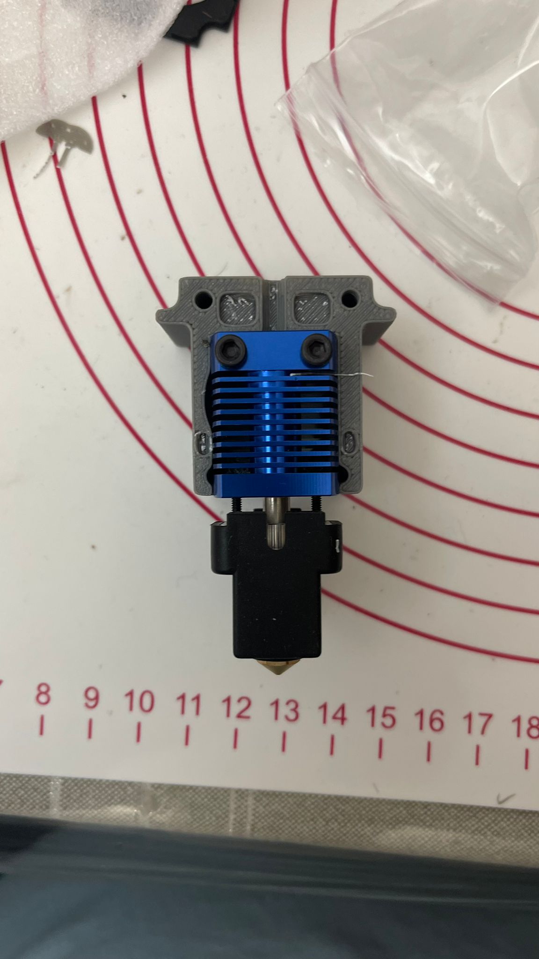
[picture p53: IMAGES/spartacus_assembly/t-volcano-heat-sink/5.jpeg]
  
</div>
<div align="center">
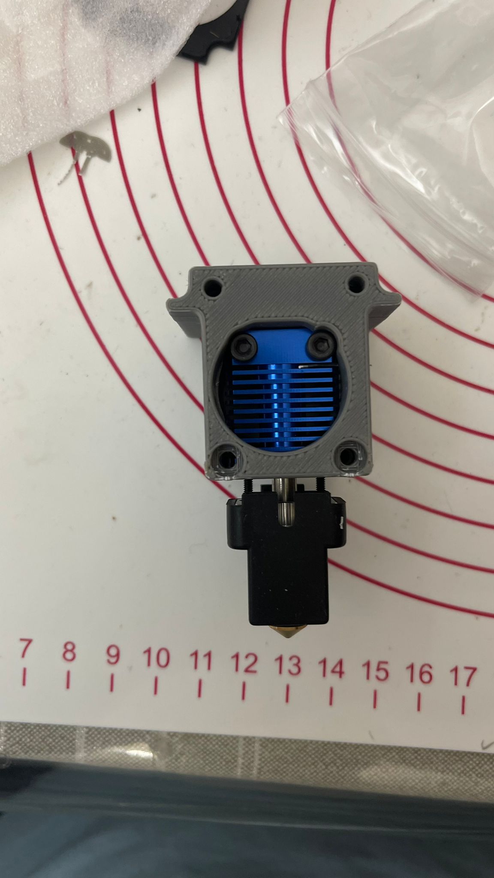
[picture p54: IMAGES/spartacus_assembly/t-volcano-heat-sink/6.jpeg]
  
</div>
<div align="center">
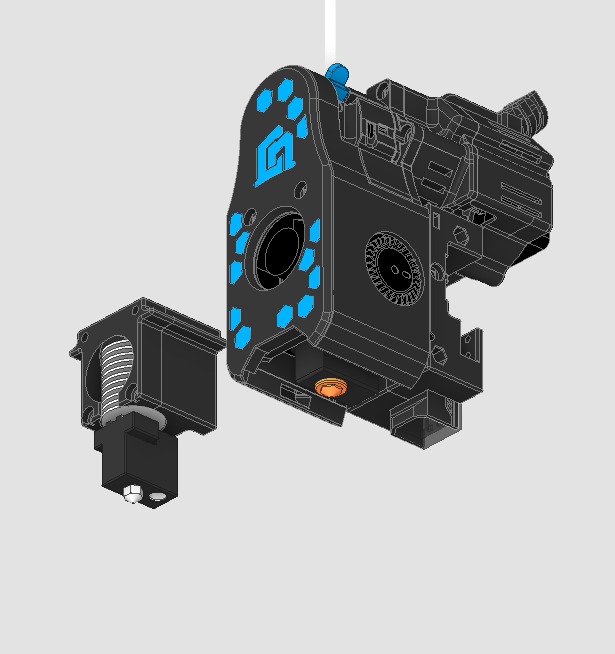
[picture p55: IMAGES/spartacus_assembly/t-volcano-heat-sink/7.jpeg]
  
</div>
<div align="center">
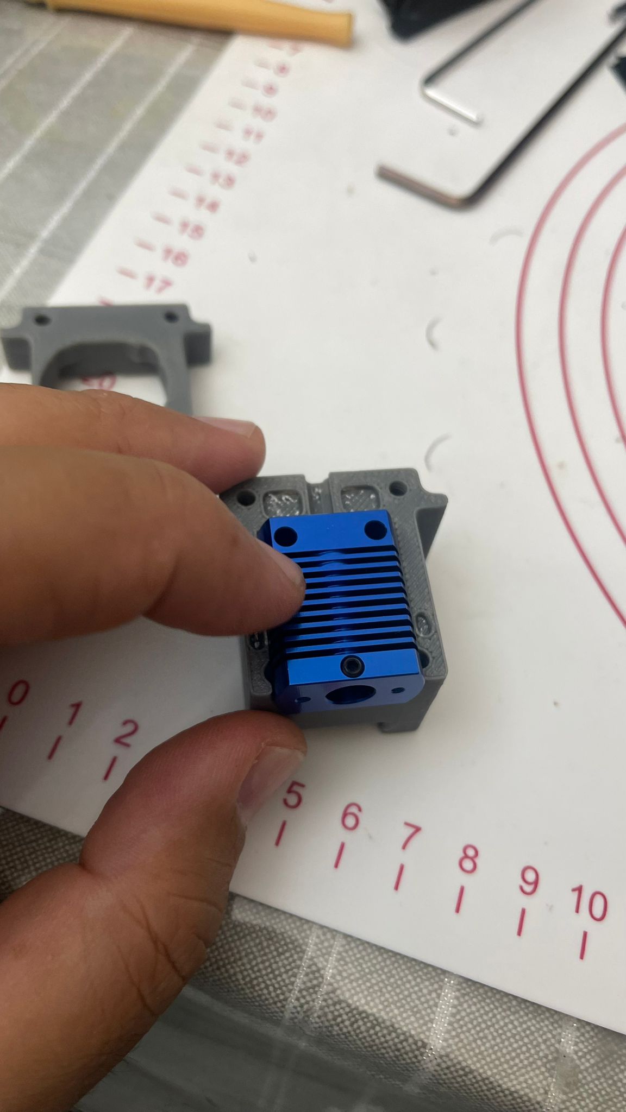
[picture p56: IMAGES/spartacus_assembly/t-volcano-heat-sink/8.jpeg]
  
</div>
<div align="center">
  
</div>
<div align="center">
  
</div>
<div align="center">
  
</div>
<div align="center">
  
</div>

Now let's prepare the Part Cooling Fans. 

<div align="center">
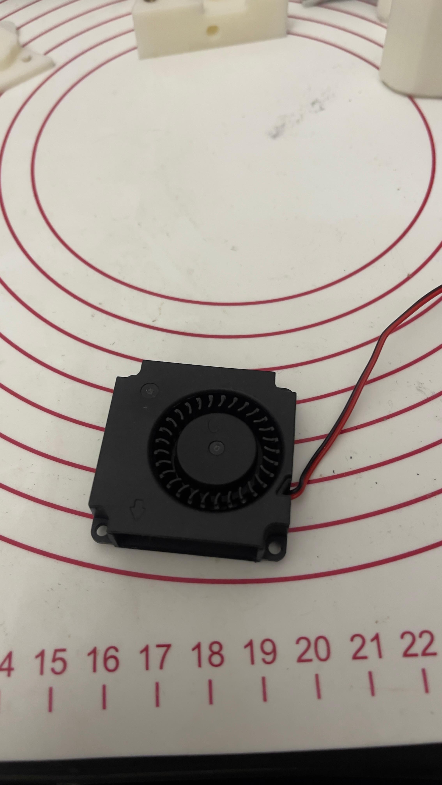
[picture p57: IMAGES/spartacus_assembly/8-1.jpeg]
  
</div>

Remove the top cover from the 4010 blower fan
<div align="center">
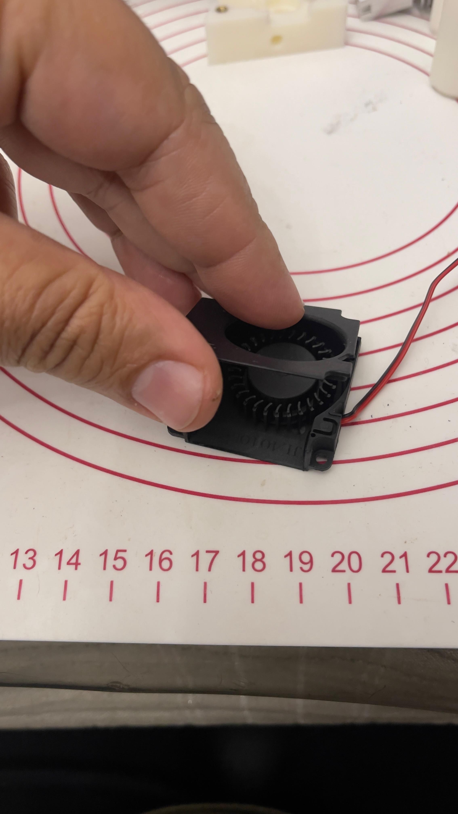
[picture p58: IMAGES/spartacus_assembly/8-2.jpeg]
  
</div>

Just pull it gently it will pop right up
<div align="center">
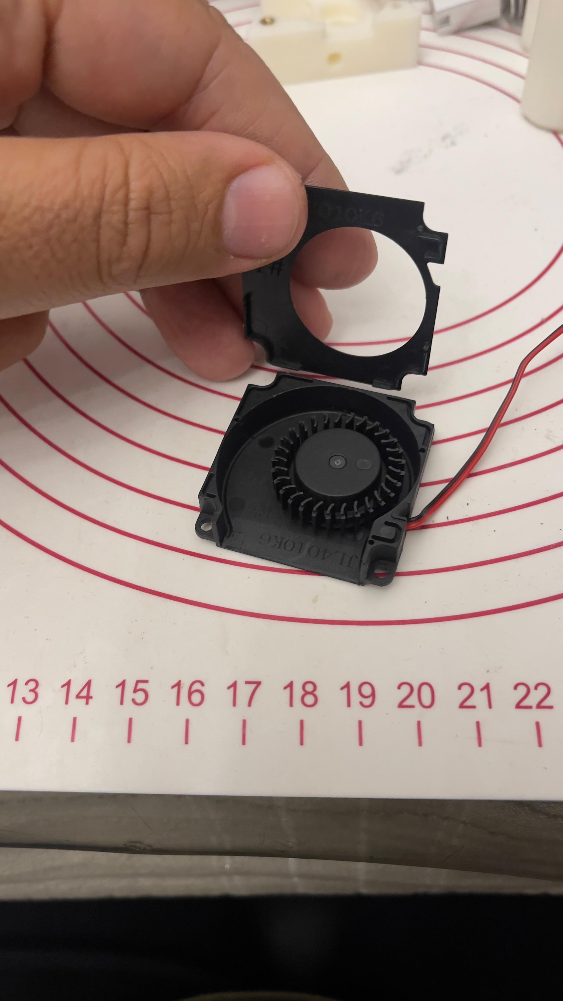
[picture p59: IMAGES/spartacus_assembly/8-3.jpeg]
  
</div>

This is how is supposed to rout the fan canles for the one that wi will mount in the right poket 
<div align="center">
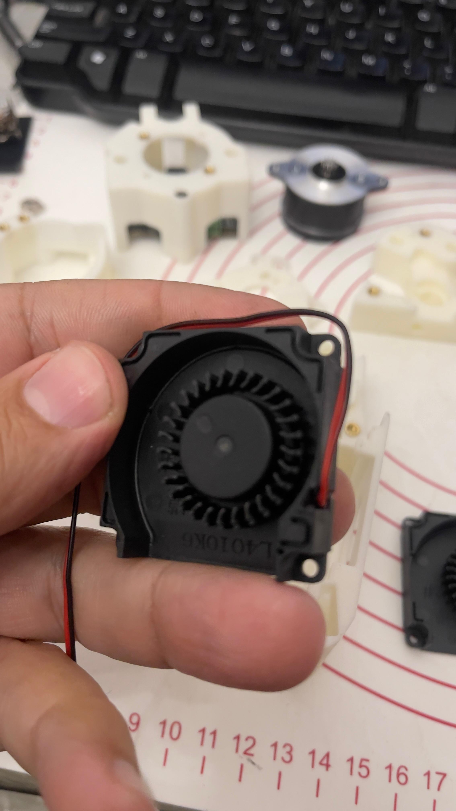
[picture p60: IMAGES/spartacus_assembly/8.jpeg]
  
</div>

Be carefule to don't pinch the cables
<div align="center">
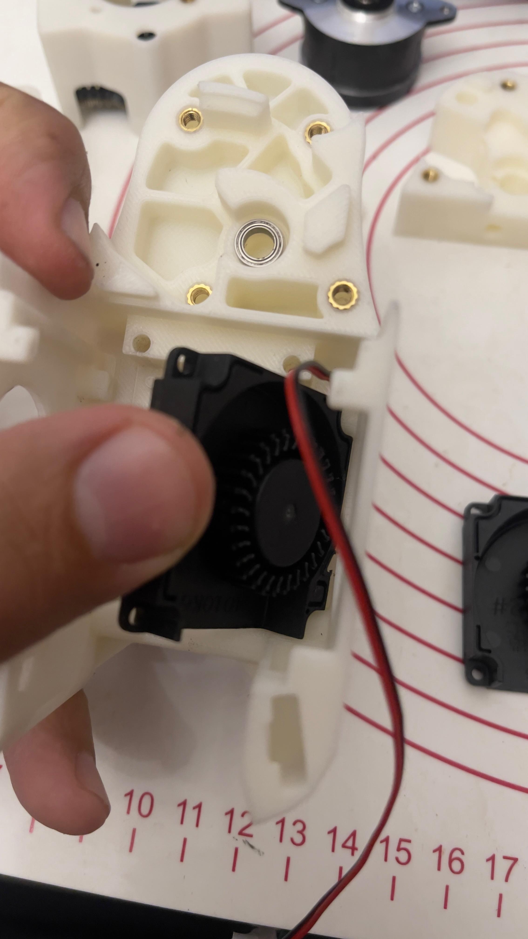
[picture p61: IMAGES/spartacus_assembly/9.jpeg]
  
</div>

<div align="center">
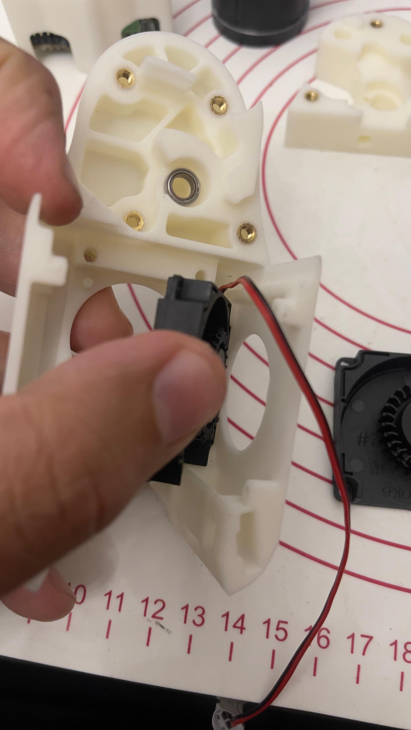
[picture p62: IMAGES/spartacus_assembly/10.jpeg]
  
</div>

This is how it should look 

<div align="center">
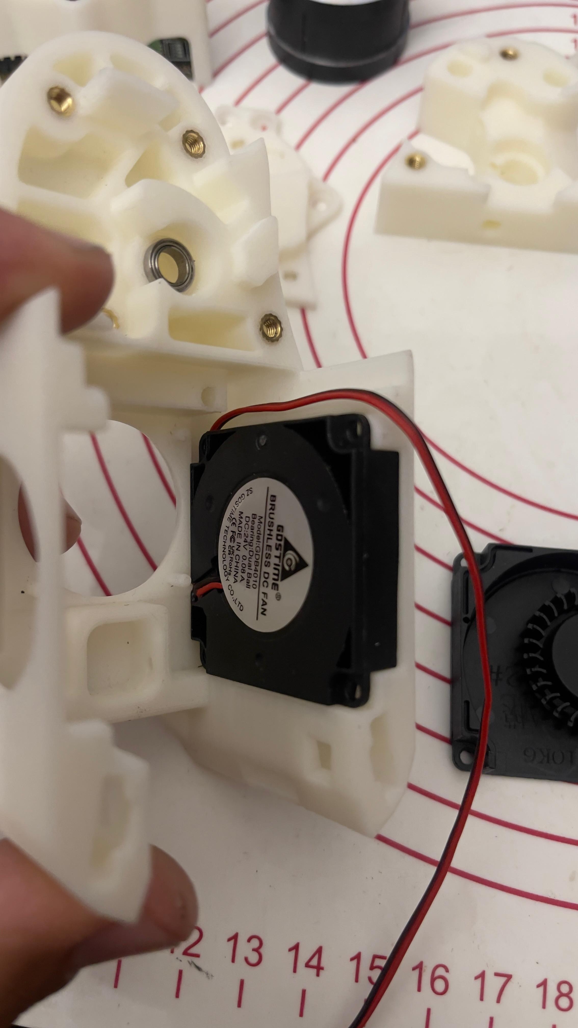
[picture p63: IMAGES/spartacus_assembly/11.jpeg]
  
</div>

Now let's mount the fan from the right side

<div align="center">
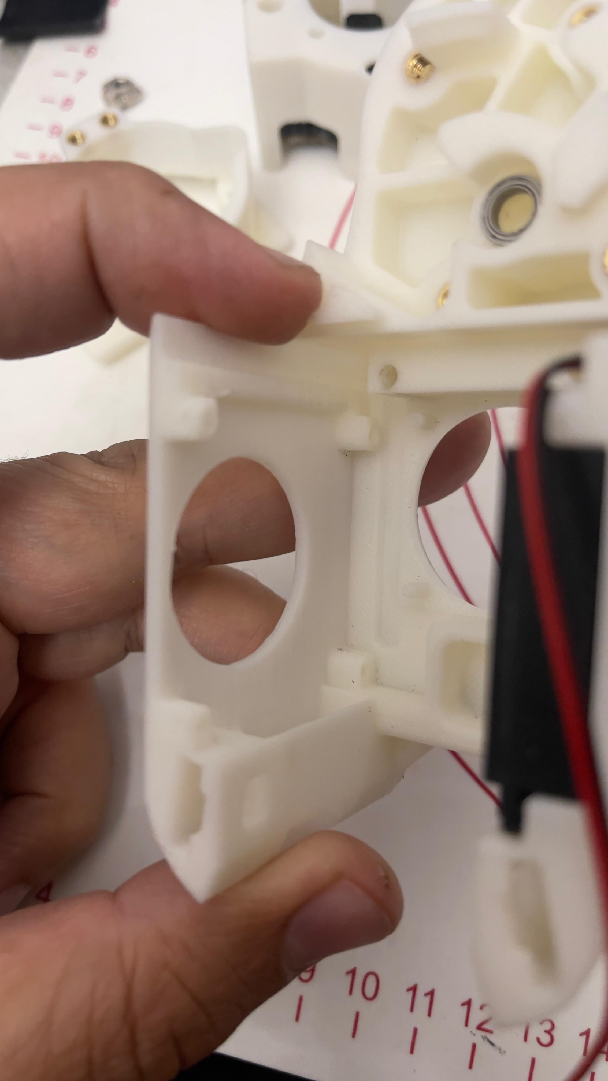
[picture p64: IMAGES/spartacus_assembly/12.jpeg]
  
</div>

Remove the lid and pop it in it oun poket 

<div align="center">
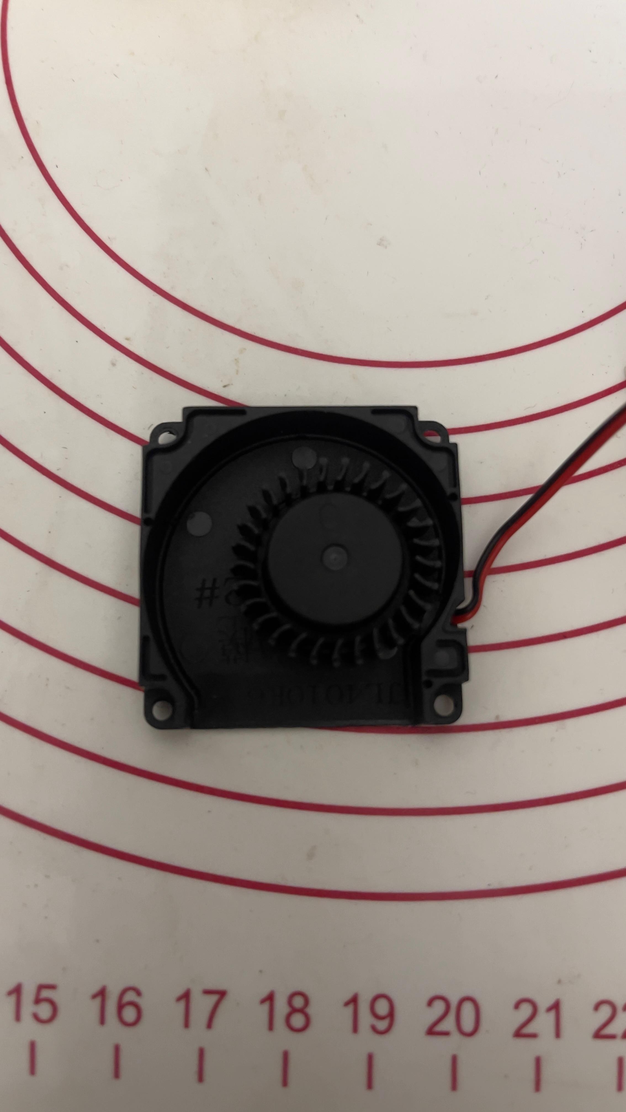
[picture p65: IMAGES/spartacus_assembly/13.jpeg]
  
</div>

Part Cooling Fan's are mounted. 

<div align="center">
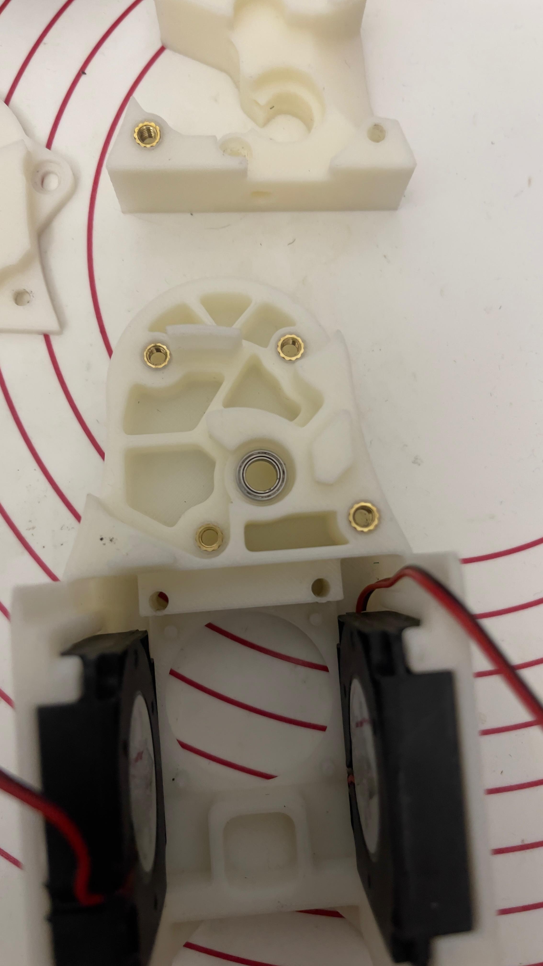
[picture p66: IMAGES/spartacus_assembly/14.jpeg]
  
</div>

Insert the 3010 hotend fan and route the cables over the right partcooling fan. it has a grove like the left one has. 

<br>

Now let's put the hotend in the right place. pay atention to the fan cable to dont pinch it, it has a gove 

<div align="center">
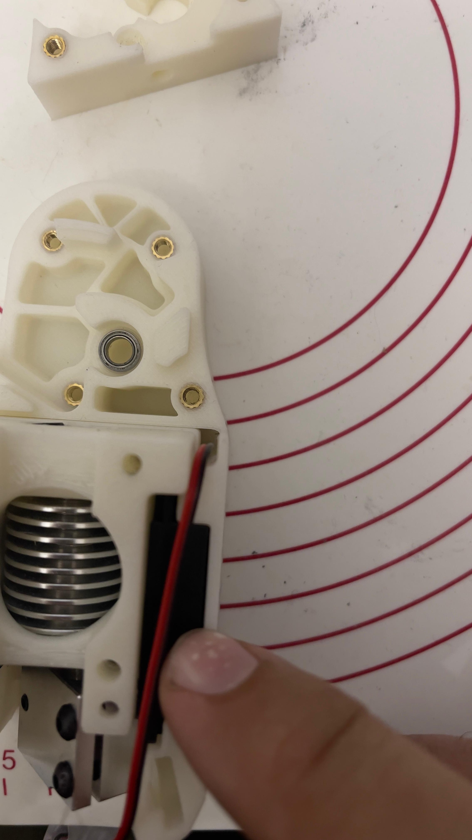
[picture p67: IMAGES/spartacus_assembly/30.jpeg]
  
</div>

<div align="center">
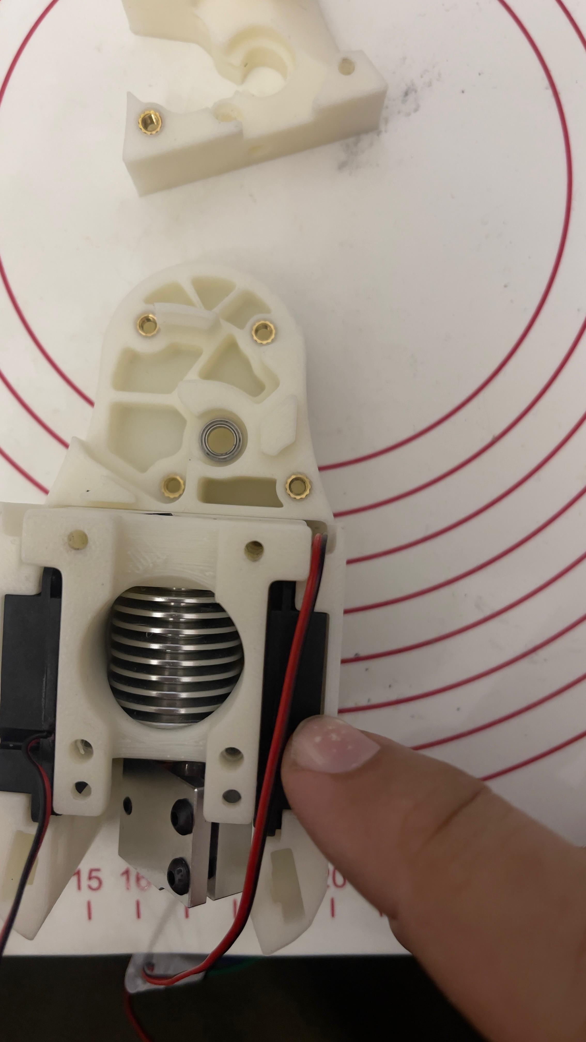
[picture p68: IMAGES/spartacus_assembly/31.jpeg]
  
</div>

Install the Iddler door, the shutter and the latch accordingly 

<div align="center">
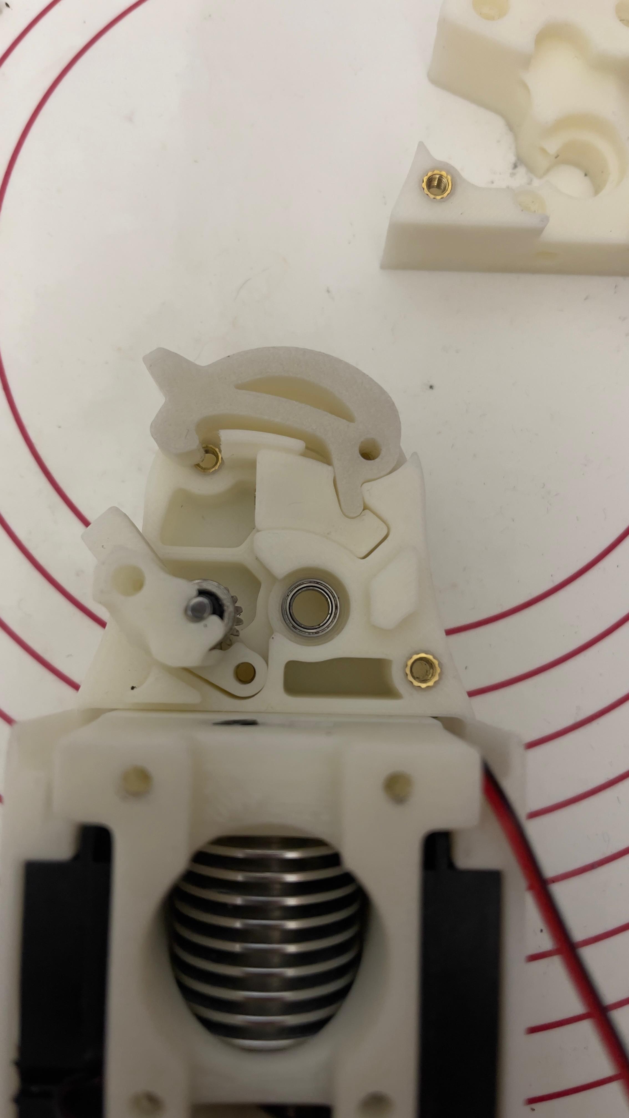
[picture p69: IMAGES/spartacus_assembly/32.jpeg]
  
</div>

Put the Extruder Main body

<div align="center">
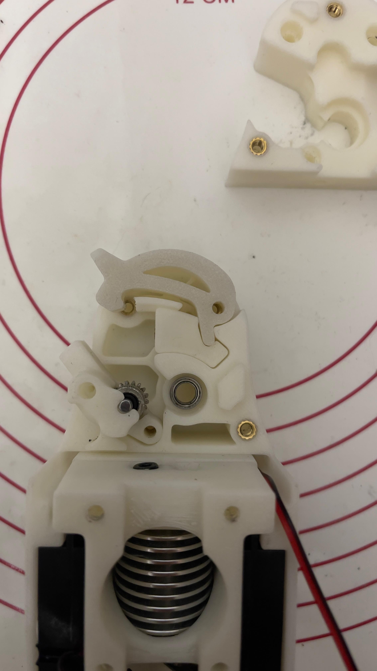
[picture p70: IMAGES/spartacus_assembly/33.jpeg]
  
</div>

M3x25

<div align="center">
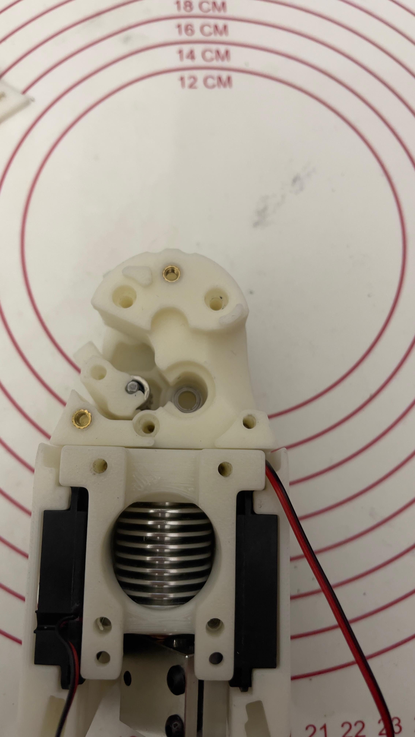
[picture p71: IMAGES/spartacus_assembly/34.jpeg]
  
</div>

M3x25

<div align="center">
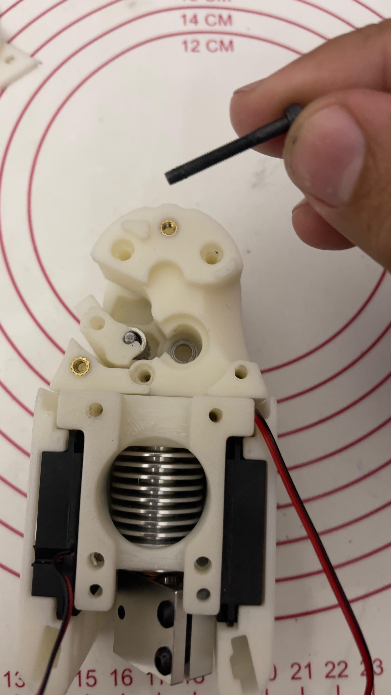
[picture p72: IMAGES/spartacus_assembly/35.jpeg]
  
</div>

<div align="center">
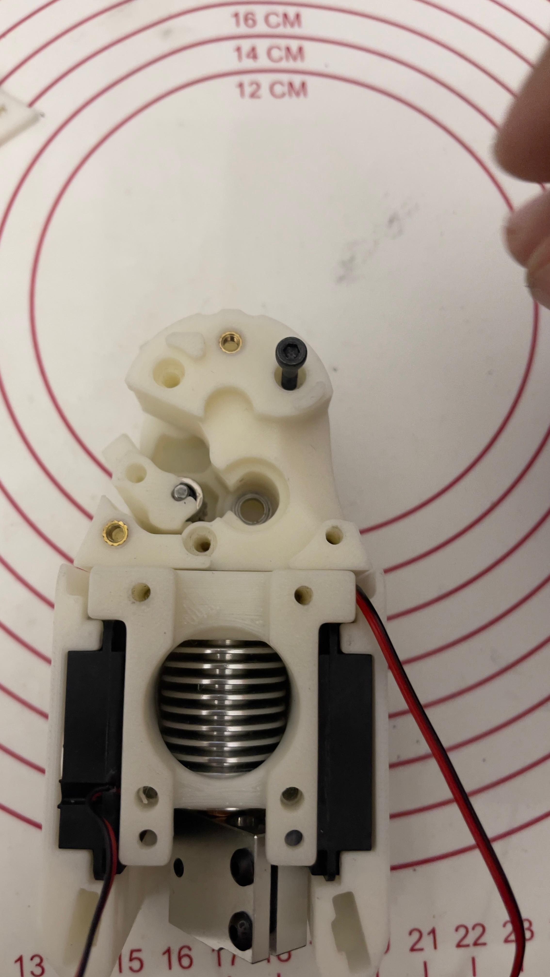
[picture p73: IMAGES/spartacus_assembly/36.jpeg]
  
</div>

M3x25

<div align="center">
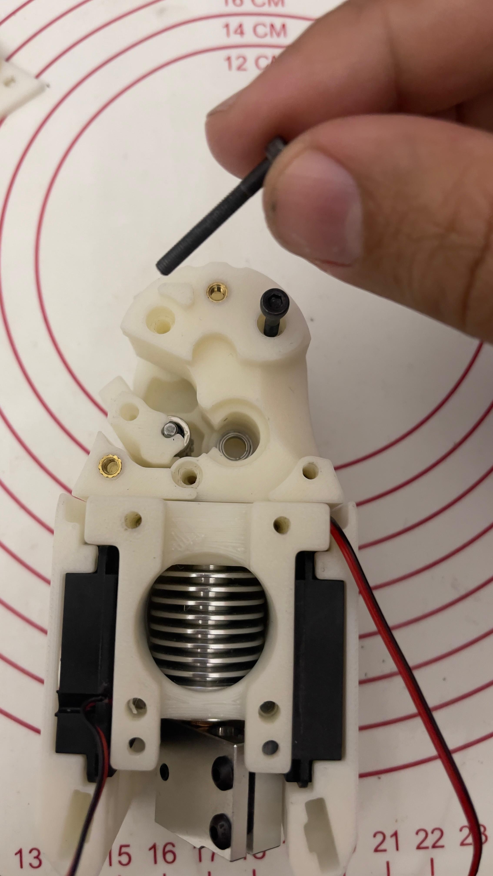
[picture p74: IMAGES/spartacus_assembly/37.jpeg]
  
</div>

<div align="center">
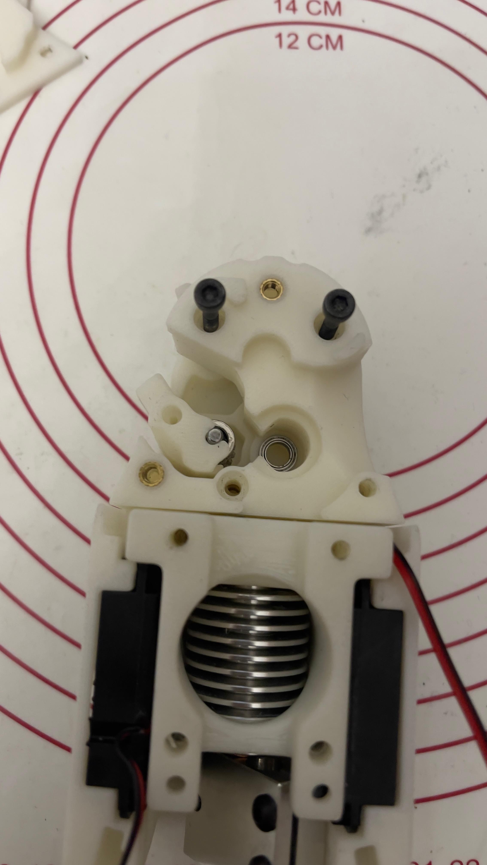
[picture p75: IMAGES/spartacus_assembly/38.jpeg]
  
</div>

M3x25
<div align="center">
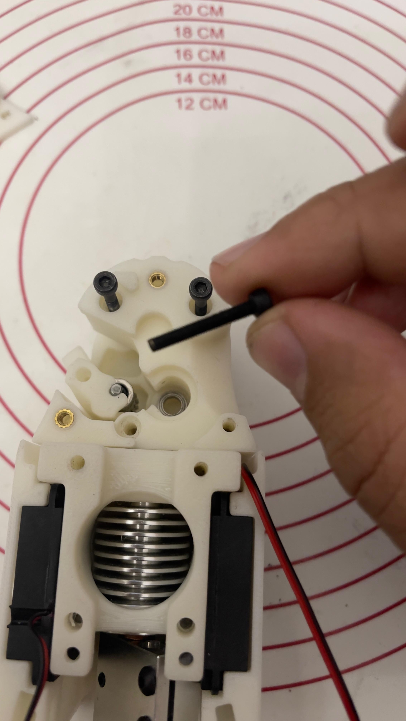
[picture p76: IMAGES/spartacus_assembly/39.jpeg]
  
</div>

<div align="center">
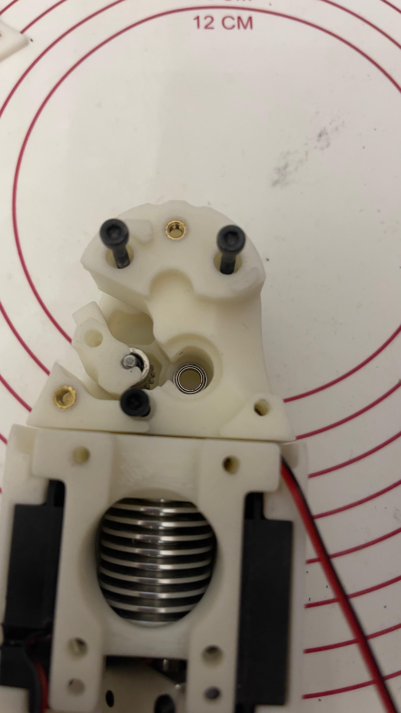
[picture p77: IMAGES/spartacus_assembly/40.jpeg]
  
</div>

Screw the 3 x M3x25

<div align="center">
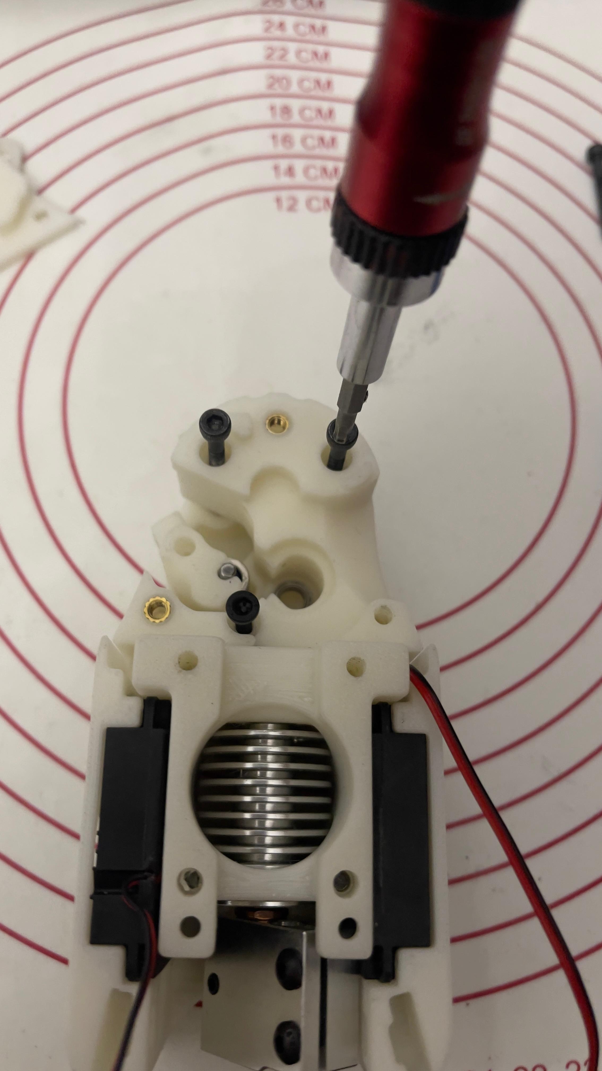
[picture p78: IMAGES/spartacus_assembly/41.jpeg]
  
</div>

<div align="center">
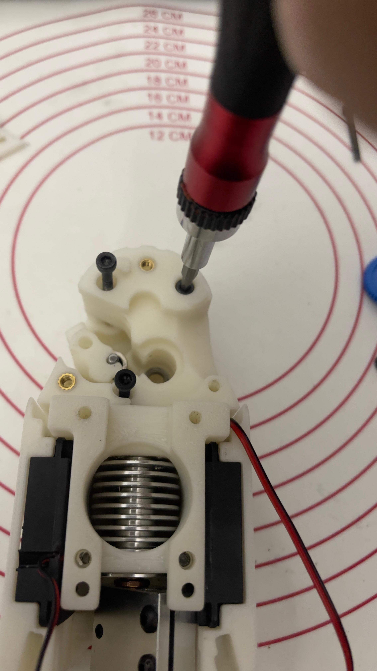
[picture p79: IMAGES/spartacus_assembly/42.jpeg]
  
</div>

<div align="center">
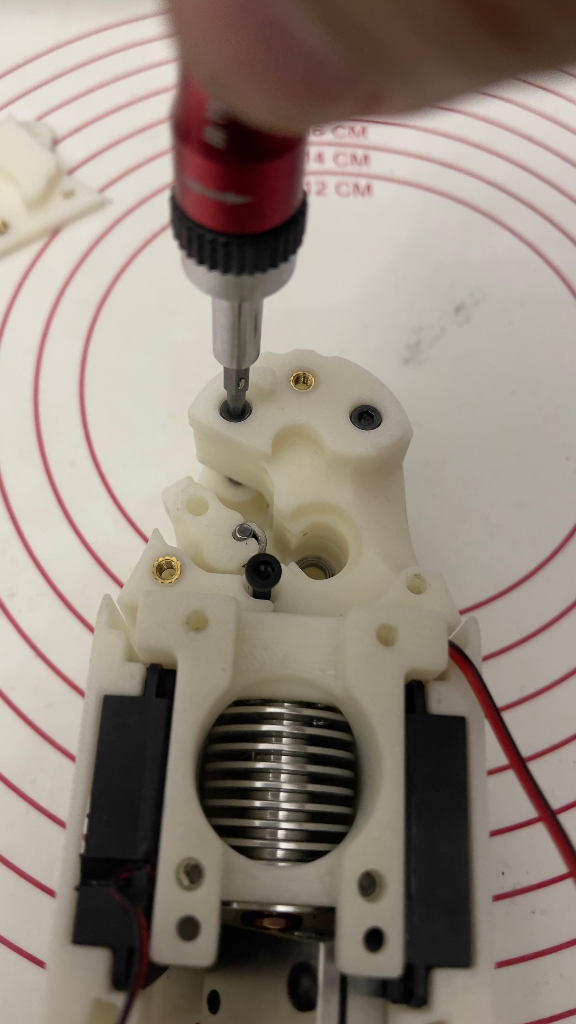
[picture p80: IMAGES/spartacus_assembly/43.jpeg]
  
</div>

<div align="center">
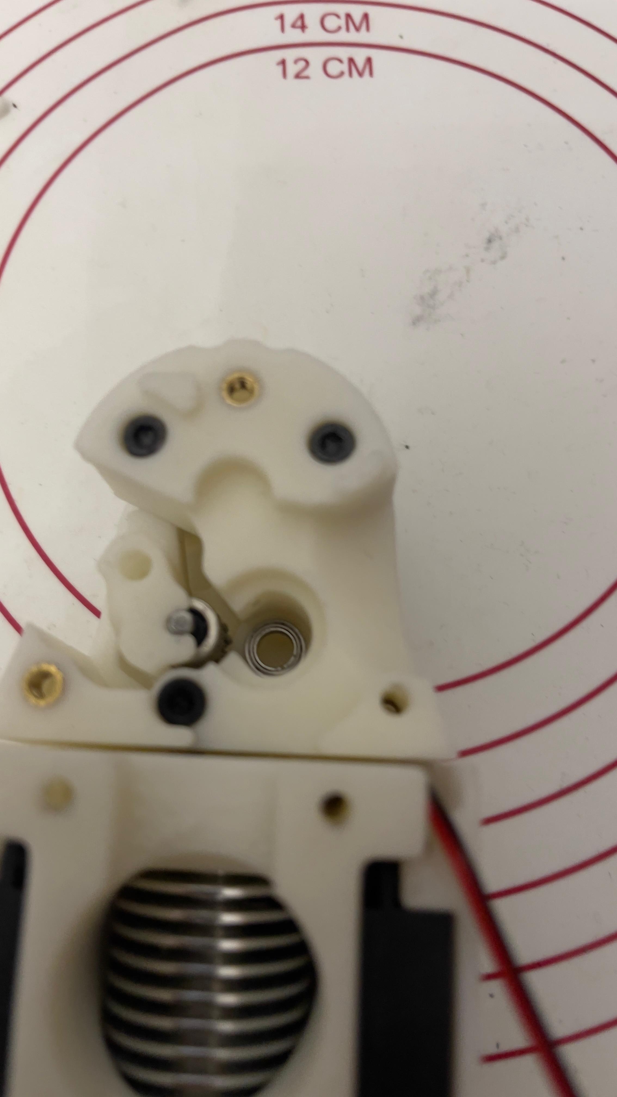
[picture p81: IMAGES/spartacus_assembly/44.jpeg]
  
</div>

<div align="center">
  
</div>

Install the BMG Gear

<div align="center">
  
</div>

<div align="center">
  
</div>

<div align="center">
  
</div>

<div align="center">
  
</div>

This is M3x20 wi will use it in the newxt step  after installing the Extruder back plate

<div align="center">
  
</div>

Install the bearing from the BMG kit in to the Extruder back plate and put it in place 

<div align="center">
  
</div>

<div align="center">
  
</div>

M3x4  countersunk screw 

<div align="center">
  
</div>

Screw it 
<div align="center">
  
</div>

<div align="center">
  
</div>

M3 x 6 

<div align="center">
  
</div>

<div align="center">
  
</div>

Sceew the M3x6 and also the M3x20 that i showed you before 

<div align="center">
  
</div>

<div align="center">
  
</div>

Insert the Nema 14 Stepper motor in to the stepper motor cover 
<div align="center">
  
</div>

<div align="center">
  
</div>

Alighn the stepper motor with bmg gear

<div align="center">
  
</div>

<div align="center">
  
</div>

<div align="center">
  
</div>

Using 2x M3x8 secure the Stepper Motor in to the back plate 

<div align="center">
  
</div>

<div align="center">
  
</div>

Using 2x M3x5 secure the stepper motor cover to the extruder back plate 

<div align="center">
  
</div>

<div align="center">
  
</div>

<div align="center">
  
</div>

Insert the EBB36 Can Toolboard in to the Can Cover 

<div align="center">
  
</div>

<div align="center">
  
</div>

Use an M3x45 screw to secure the Can cover trowgh the stepper motor cover in to the Extruder back plate. 

<div align="center">
  
</div>

<div align="center">
  
</div>

<div align="center">
  
</div>

Using 2xM3x16 secure the can cover in to the stepper motor cover

<div align="center">
  
</div>

<div align="center">
  
</div>

<div align="center">
  
</div>

Here at the back i mounted only 2 set insets to secure the 3010 fan to cool down the canboard and the driver for the extruder. 

<div align="center">
  
</div>

Down at the bottom we have space for 2 round pcb 5050 neopixels I use RGBW 

<div align="center">
  
</div>

Insert the spring loaded screw to secure the iddler door 

<div align="center">
  
</div>

we are missing the 3010 hotend fan but you get the idea this is how it supposed to look when its ready. 

<div align="center">
  
</div>

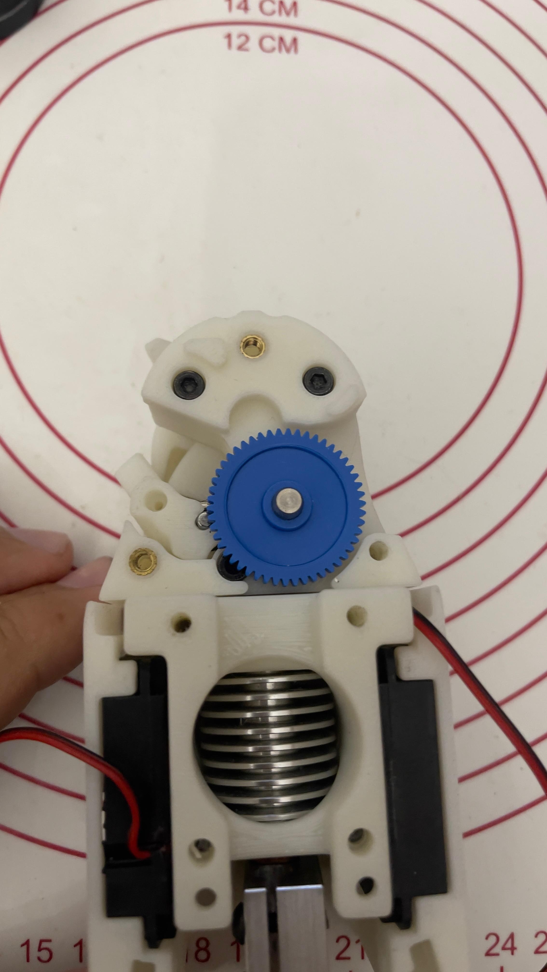
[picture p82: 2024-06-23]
IMAGES/spartacus_assembly/20.jpeg

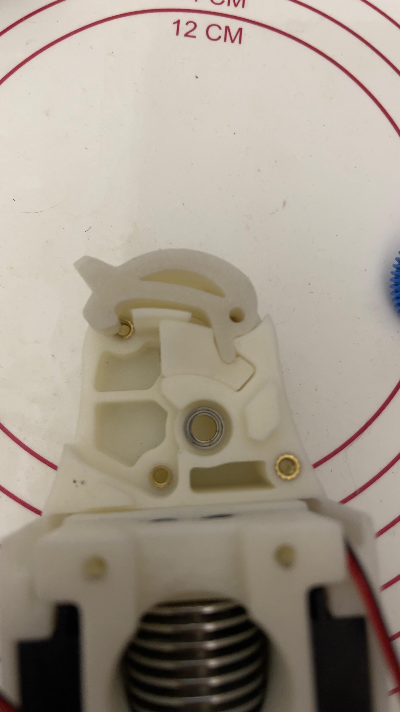
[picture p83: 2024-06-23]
IMAGES/spartacus_assembly/16.jpeg

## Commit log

2024-06-24 Update 7 Spartacus Stealth-Changer-462 mm wide png.png
2024-07-17 Update assembly.md
    simplify the assembly with the new hot ends
2024-07-17 added eddy probe
    added eddy probe support and t-volcano with Creality heat sink hot-end. + pictures
2024-07-17 Update toolhead_assembly.md
    we have added pictures in how to use the Creality heat sink that it is coming with the T-Volcano that we recommend to use as a hot-end
2024-10-15 added Short dock
    We have added the Spartacus BMG and LGX Short Dock
    and with the short dock we gain almost 53mm on Z
